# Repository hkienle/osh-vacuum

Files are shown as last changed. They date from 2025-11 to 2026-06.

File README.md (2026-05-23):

# Open Source Vacuum Cleaner

> **📝 Note:** This repository is currently being populated with information. Content and documentation are being added progressively.

---

## About

This repository contains the Open Source Vacuum Cleaner project, an open-source hardware and software solution for building custom vacuum cleaners. The project includes complete PCB designs, ESP32-S3 based firmware, and a web-based control interface.

The system is designed to control high RPM impellers for vacuum machines, featuring motor control, real-time monitoring (RPM, temperature, battery voltage), WiFi connectivity, and a modern web interface.

## Project Structure

```
osh-vacuum/
├── Hardware/              # PCB designs and hardware documentation
│   └── PCB_Bench_Prototype/  # Benchtop prototype board design
│       ├── README.md         # Hardware documentation and BOM
│       └── Production/       # Manufacturing files
├── Firmware/              # ESP32-S3 firmware and web interface
│   ├── README.md          # Firmware documentation, pin assignments, build instructions
│   ├── src/               # Firmware source code
│   └── ui/                # React-based web interface
└── README.md              # This file
```

### Hardware

The hardware design includes:
- ESP32-S3 microcontroller with WiFi and BLE
- Motor control with Infineon ProFet for high-side switching
- 5 RGB LEDs (WS2812B) and 3 customizable buttons
- Battery voltage monitoring (15-32V input)
- Temperature monitoring via thermistor
- Tachometer input for RPM measurement
- Break-off sections for flexible form factors

📖 **[Hardware Documentation →](Hardware/PCB_Bench_Prototype/README.md)**

### Firmware

The firmware provides:
- Motor speed control (0-100% PWM)
- Real-time monitoring (RPM, temperature, battery voltage)
- WiFi access point with web server
- WebSocket communication for live updates
- React-based web interface

📖 **[Firmware Documentation →](Firmware/README.md)**

## Quick Start

1. **Hardware**: Review the [PCB documentation](Hardware/PCB_Bench_Prototype/README.md) for board assembly
2. **Firmware**: Follow the [firmware build and upload instructions](Firmware/README.md)
3. **Frontend**: Build and upload the web interface as described in the firmware README

## Status

**Current Phase**: Benchtop Prototype

The current board design is untested and represents the benchtop prototype phase. All designs and firmware are provided as-is for development and testing purposes.

## License

This project is licensed under the **CERN Open Hardware Licence - Strongly Reciprocal (CERN OHL-S v2)**.

The full license text is available at: [cern_ohl_s_v2.txt](https://gitlab.com/ohwr/project/cernohl/-/wikis/uploads/819d71bea3458f71fba6cf4fb0f2de6b/cern_ohl_s_v2.txt)

---

*More information at [HackMD - Team Intuity](https://hackmd.io/@team-intuity) and [HackMD - hkienle](https://hackmd.io/@hkienle)*

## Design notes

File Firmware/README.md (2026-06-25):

# OSH Vacuum — Firmware

ESP32-S3 firmware for open-source high-RPM impeller vacuum machines.

→ **[Setup Guide](Setup.md)** — install, configure, build and flash  
→ **[Usage Guide](usage.md)** — operate the device, change settings

---

## What this firmware does

- **Motor control** — PWM-based speed control (0–100%) with ProFet high-side switching, configurable speed steps and minimum duty floor.
- **Two trigger modes** — Hold (hold-to-start, tap-to-stop) or Double-Press (momentary + latch).
- **Safety** — Automatic motor cutoff after a configurable runtime limit and on NTC over-temperature.
- **Sensors** — Real-time RPM (tachometer), motor NTC temperature, pack voltage, battery SOC, and ESP32 internal die temperature.
- **Battery SOC** — Rolling OCV-curve estimation from pack voltage ÷ series cell count. Paused while motor runs.
- **OLED display** — Supports 0.91" (SSD1306, 128×32) and 1.5" (SSD1327, 128×128) Waveshare I2C modules. Shows speed bar, live sensor value, battery icon, and OTA progress overlay.
- **LED strip** — 5 × WS2812B indicate WiFi status on boot, then display speed tier (blue = idle, red = motor active).
- **Dev / Settings menu** — 13-page on-device menu (hold UP+DOWN) with status pages and all configurable parameters. Settings persist in NVS.
- **WiFi** — STA mode with soft-AP fallback. mDNS via configurable hostname.
- **Web interface** — React SPA served from LittleFS on port 80. Real-time control and monitoring.
- **WebSocket telemetry** — JSON broadcast on port 81 at ~4 Hz (temp, battery, RPM, speed, motor state, SOC).
- **OTA updates** — ArduinoOTA (espota) for wireless firmware flashing via PlatformIO.
- **Light sleep** — Automatic power-saving after configurable inactivity timeout; wake on any button.

---

## Hardware at a glance

| GPIO | Function |
|---|---|
| 4 | Motor NTC thermistor (ADC) |
| 5 | Motor PWM output (LEDC, 1 kHz, 8-bit) |
| 6 | Battery voltage ADC (330 kΩ / 22 kΩ divider) |
| 7 | MOSFET / ProFet enable |
| 8 | I2C SCL (OLED) |
| 9 | I2C SDA (OLED) |
| 16 | Tachometer FG input (interrupt) |
| 39 | WS2812B LED data (5 LEDs) |
| 40 | Button DOWN |
| 41 | Button UP |
| 42 | Button TRIGGER |

---

## Project structure

```
Firmware/
├── platformio.ini                    # Build environments
├── data/                             # LittleFS contents (built web UI)
├── ui/                               # React frontend source
└── src/
    ├── main.cpp                      # Setup, loop, telemetry, safety
    ├── settings/                     # NVS runtime settings + compile-time config
    ├── motor/                      # Dispatcher + MOTOR_DRIVERS.md
    ├── motor_generic_pwm/          # LEDC PWM (default backend)
    ├── motor_xiaomi_g/             # Xiaomi G ESC: xiaomi_g_protocol, xiaomi_g_uart, driver
    ├── button/                       # Debounced inputs, trigger modes, dev menu
    ├── led/                          # WS2812B FastLED patterns
    ├── display/                      # Display facade + telemetry struct
    ├── display_oled/                 # SSD1306 128×32 rendering
    ├── display_waveshare_091_i2c/    # Adapter → display_oled
    ├── display_waveshare_15_i2c/     # SSD1327 128×128 rendering
    ├── battery/                      # ADC voltage + calibration
    ├── battery_soc/                  # OCV-based SOC estimation
    ├── temperature/                  # NTC thermistor (beta equation)
    ├── tachometer/                   # FG pulse counting → RPM
    ├── mcu_temp/                     # ESP32 internal die temperature
    ├── wifi/                         # STA/AP, mDNS
    ├── webserver/                    # AsyncWebServer, LittleFS
    ├── websocket/                    # WebSocket server, JSON telemetry
    ├── ota/                          # ArduinoOTA + display overlay
    └── power/                        # Light sleep, GPIO wakeup
```

---

## Libraries

| Library | Version | Purpose |
|---|---|---|
| FastLED | ^3.6.0 | WS2812B control |
| ArduinoJson | ^6.21.3 | JSON |
| WebSockets | ^2.4.1 | WebSocket server |
| ESPAsyncWebServer | ^3.8.1 | HTTP server |
| AsyncTCP | ^3.4.9 | Async TCP |
| ArduinoOTA | built-in | Wireless upload |
| Adafruit SSD1306 | latest | 0.91" OLED driver |
| Adafruit SSD1327 | latest | 1.5" OLED driver |
| Adafruit GFX Library | ^1.12.1 | OLED graphics primitives |

---

## License

Part of the Open Source Vacuum Cleaner project.

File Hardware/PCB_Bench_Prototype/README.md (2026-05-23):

# PCB Bench Prototype

**Status: Untested** - This board is currently in the benchtop prototype phase of the Open Source Vacuum Cleaner project and has not yet been tested.

## Overview

This PCB is designed to control a high RPM impeller for vacuum machines. It provides comprehensive control and monitoring capabilities with modern connectivity options.

The design features break-off sections that allow users to build their own vacuum cleaner in whichever shape they like. These break-off sections enable flexible placement of LEDs and buttons to suit various form factors and user preferences.

## Features

- **Connectivity**
  - BLE (Bluetooth Low Energy)
  - WiFi connectivity
  
- **Power Management**
  - USB-C connector for programming
  - Voltage regulation from 15-32V down to 5V and 3.3V
  - Battery voltage monitoring (reads voltage of connected battery)
  
- **User Interface**
  - 5 RGB LEDs (WS2812B)
  - 3 customizable buttons
  
- **Motor Control & Monitoring**
  - Automotive ProFet by Infineon for high-side switching (required for ESC control, replacing classic MOSFETs)
  - Level-shifted 3.3V and 5V PWM output
  - Voltage-divided input for 5V tachometer signal
  - 10kΩ thermistor reading capability
  
- **Expansion**
  - All unused and safe GPIOs are broken out
  - I2C, SPI, and UART interfaces available

## Bill of Materials (BOM)

| Designator | Footprint | Quantity | Value | LCSC Part # |
|---|---|---|---|---|
| C1, C7, C8, C9 | 0805 | 4 | 22µF | - |
| C10, C11, C12, C13, C14, C2, C5 | 0805 | 7 | 0.1µF | - |
| C3 | 0805 | 1 | 1µF | - |
| C4 | 0805 | 1 | 10nF | - |
| C6 | 0805 | 1 | 10µF | - |
| LED1, LED2, LED3, LED4, LED5 | LED-SMD_4P-L5.0-W5.0-TL-1 | 5 | WS2812B-V5/W | C2874885 |
| R10 | 0805 | 1 | 330kΩ | - |
| R11 | 0805 | 1 | 33kΩ | - |
| R12 | 0805 | 1 | 56kΩ | - |
| R13 | 0805 | 1 | 4.7kΩ | - |
| R14, R16 | 0805 | 2 | 5.1kΩ | - |
| R15, R17, R18, R3, R5, R6, R7, R8 | 0805 | 8 | 10kΩ | - |
| R4 | 0805 | 1 | 220Ω | - |
| R9 | 0805 | 1 | 22kΩ | - |
| SW1, SW2 | SW-SMD_4P-L4.2-W3.2-P2.15-LS4.6 | 2 | RKB2SJK250SMTRLFS | C2927789 |
| SW6, SW7, SW8 | KEY-SMD_4P-L5.2-W5.2-P3.7-LS6.4-TL | 3 | TS-1076S-A7B3 | C492950 |
| U1 | WIRELM-SMD_ESP32-S3-WROOM-1 | 1 | ESP32-S3-WROOM-1(N16R2) | C2913205 |
| U2 | PG-HSOF-8_L10.4-W9.8-BTH500151LUAAUMA1 | 1 | BTH500151LUAAUMA1 | C36571656 |
| U3 | SOT-223-4_L6.5-W3.5-P2.30-LS7.0-BR | 1 | LD1117S33CTR | C35879 |
| U4, U5 | SC-70-5_L2.0-W1.3-P0.65-LS2.1-BL | 2 | SN74AHCT1G125DCKR | C350557 |
| U8 | PWRM-TH_L11.7-W7.5_TSR1-2450 | 1 | TSR 1-2450_C6886877 | C6886877 |
| U9 | USB-SMD_TYPE-C16PIN-1 | 1 | 12402012E212A | C5150972 |

## Images

### Front View
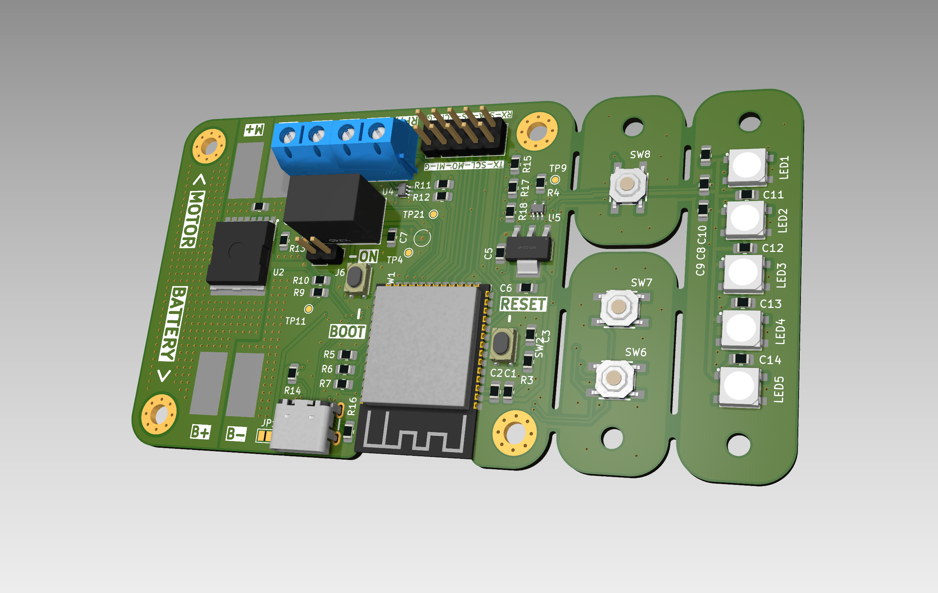
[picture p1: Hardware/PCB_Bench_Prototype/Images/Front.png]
Front View


### Back View
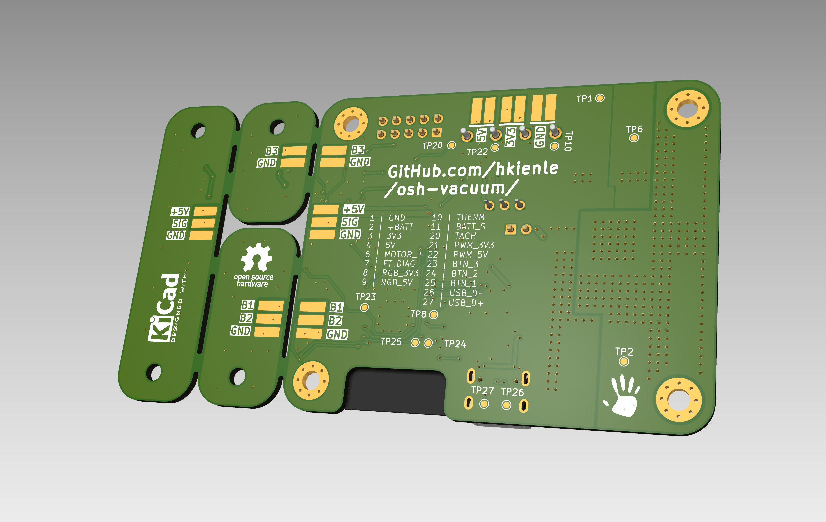
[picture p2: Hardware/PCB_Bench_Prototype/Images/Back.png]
Back View


### PCB Layout
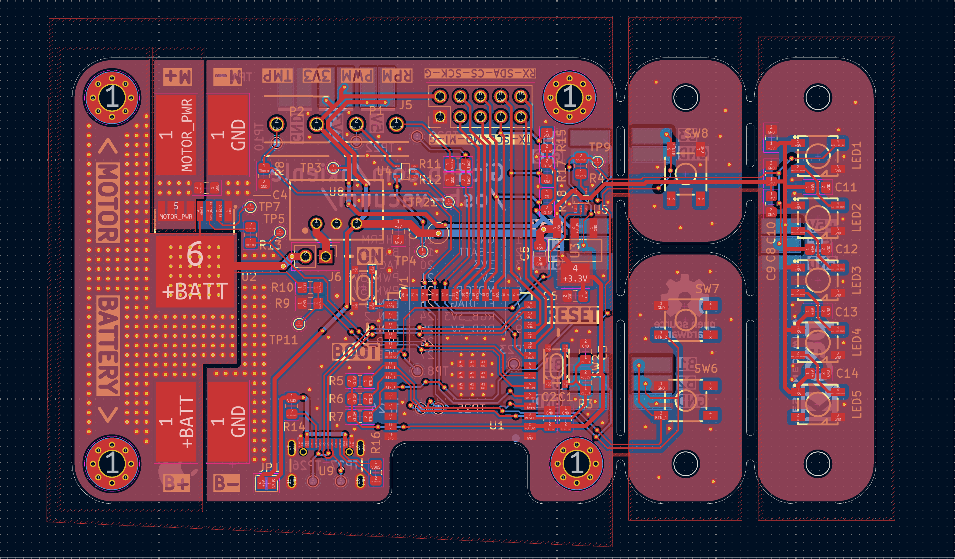
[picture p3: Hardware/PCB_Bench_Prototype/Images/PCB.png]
PCB Layout


## License

This hardware design is licensed under the **CERN Open Hardware Licence - Strongly Reciprocal (CERN OHL-S v2)**.

The full license text is available at: [cern_ohl_s_v2.txt](https://gitlab.com/ohwr/project/cernohl/-/wikis/uploads/819d71bea3458f71fba6cf4fb0f2de6b/cern_ohl_s_v2.txt)

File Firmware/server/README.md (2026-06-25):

# Hosted UI (separate from ESP web server)

The **hosted** React app is **not** the same as the UI baked into the ESP32 (LittleFS).

| | Embedded (ESP) | Hosted (this server) |
|---|---|---|
| **URL** | `http://osh-vac.local` | `http://your-server:8080` |
| **Static files** | LittleFS on ESP | `Firmware/ui/dist/` |
| **Device link** | Direct `ws://osh-vac.local:81` | Same-origin `/device-ws` proxy → vacuum |
| **Deploy** | `npm run build:esp32` + `uploadfs` | `npm run build:server` + run server below |

Browsers block an **HTTPS** hosted page from opening `ws://192.168.x.x:81` directly. The hosted server proxies WebSocket so the app stays same-origin.

## Quick start (local)

```bash
# 1. Build the hosted UI bundle
cd Firmware/ui
npm install
npm run build:server

# 2. Run the hosted server (static files + WebSocket proxy)
cd ../server
npm install
npm start
```

Open **http://localhost:8080** (not the ESP address).

1. Sidebar → **WiFi** (Bluetooth is not used yet)
2. Enter **`osh-vac.local`** or the vacuum's IP
3. **Connect via WiFi**

## Dev mode (Vite)

```bash
cd Firmware/ui
npm run dev
```

Open **http://localhost:5173** — the dev server includes the same `/device-ws` proxy.

## Production deploy

1. `npm run build:server` in `Firmware/ui`
2. Deploy `Firmware/ui/dist/` **and** run `Firmware/server/hosted.mjs` on your host (Node.js)
3. Put nginx/Caddy in front for HTTPS; ensure WebSocket upgrade works on `/device-ws`

**GitHub Pages (production):** see [docs/GITHUB_PAGES.md](../docs/GITHUB_PAGES.md) — static deploy at `https://connect.caznic.xyz` (BLE transport).

**Self-hosted (WiFi proxy):** run this server on your own host, or use `Firmware/Dockerfile` / `nixpacks.toml`.

Environment:

| Variable | Default | Purpose |
|---|---|---|
| `PORT` | `8080` | HTTP port |
| `UI_DIR` | `../ui/dist` | Path to built React app |

## ESP firmware

The vacuum still needs WiFi + WebSocket on port **81** (standard `esp32-s3` / `esp32-s3-ota` build). OTA only updates firmware; it does **not** update this hosted UI.

```bash
cd Firmware
pio run -e esp32-s3-ota -t upload
```

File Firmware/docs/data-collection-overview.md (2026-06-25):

# Data Collection Overview — Open Source Vacuum Cleaner

Comprehensive overview of all data the current build can collect — what's measured, what's computed, what's exposed, and what's hidden. Based on firmware source analysis (`Firmware/src/`) and PCB schematic (`Hardware/PCB_Bench_Prototype/`).

---

## 1. Directly Measured Sensor Data

Physical sensors connected to the ESP32-S3 via GPIO or internal peripherals.

| Data Point | Source / Sensor | GPIO | Update Rate | Resolution / Notes | Code Location |
|---|---|---|---|---|---|
| **Motor RPM** | FG tachometer pulse (ISR) | 16 | 5 Hz (200 ms) | 1 pulse/rev (`PULSES_PER_REV = 1`), ISR counting → Hz → RPM | `tachometer/tachometer.cpp` |
| **Motor temperature** | NTC thermistor 10k, Beta=3950 | 4 | 4 Hz (250 ms) | 8x oversampling, Beta equation, 12-bit ADC (0–4095), `SERIES_R = 10k` | `temperature/temperature.cpp` |
| **Pack voltage** | ADC voltage divider 330k/22k (ratio 16:1) | 6 | 10 Hz (100 ms) | 8x oversampling via `analogReadMilliVolts()`, 2-point calibrated (12V/36V), range 0–60V | `battery/battery.cpp` |
| **Pack voltage (raw)** | Same ADC, pre-calibration | 6 | 10 Hz | Uncalibrated divider output, available via `getBatteryVoltageRaw()` | `battery/battery.cpp:80-82` |
| **MCU die temperature** | ESP32-S3 internal sensor | internal | 2 Hz (500 ms) | `temperatureRead()` (Arduino core), returns °C or `NAN` before first read | `mcu_temp/mcu_temp.cpp` |
| **Battery SOC** | Derived from pack voltage | — | 2 Hz (100 ms sampling) | 21-point Li-ion OCV curve, rolling avg of 50 samples, **paused while motor runs + 2s cooldown** | `battery_soc/battery_soc.cpp` |

### Sensor Calibration Parameters

| Parameter | Value | Location |
|---|---|---|
| Voltage divider ratio | 330kΩ / 22kΩ = 16.0 | `battery/battery.cpp:7-9` |
| Voltage calibration points | 12.000V → 11.640V, 36.000V → 35.280V | `battery/battery.cpp:12-16` |
| NTC R0 | 10kΩ at 25°C | `temperature/temperature.cpp:15` |
| NTC Beta | 3950 | `temperature/temperature.cpp:17` |
| NTC series resistor | 10kΩ | `temperature/temperature.cpp:9` |
| Tachometer pulses/rev | 1 (configurable) | `tachometer/tachometer.cpp:7` |
| SOC OCV curve | 21 breakpoints, 3.520V (0%) → 4.080V (100%) | `battery_soc/battery_soc.cpp:21-28` |

---

## 2. Computed & Derived Data

Values calculated from sensor inputs, not directly measured.

| Data Point | Derivation | Update Rate | Persisted | Code Location |
|---|---|---|---|---|
| **Battery SOC %** | Pack voltage ÷ series cells → per-cell voltage → OCV curve interpolation → rounded 0–100 | 2 Hz (when motor off) | No (RAM only) | `battery_soc/battery_soc.cpp:128-143` |
| **Max RPM (session)** | Peak RPM while motor active | On motor on/off edge | Yes — NVS key `mstat_rpm` | `maximum_stats/maximum_stats.cpp:106-112` |
| **Max pack voltage (session)** | Peak voltage while motor active | On motor on/off edge | Yes — NVS key `mstat_vf` | `maximum_stats/maximum_stats.cpp:113-117` |
| **Max motor temp (session)** | Peak NTC temp while motor active | On motor on/off edge | Yes — NVS key `mstat_tf` | `maximum_stats/maximum_stats.cpp:118-124` |
| **Calibrated voltage** | Raw ADC → divider scale → 2-point linear correction | 10 Hz | No | `battery/battery.cpp:62-72` |
| **Cell voltage** | Pack voltage ÷ `batterySeriesCells` (1–32) | On SOC sample | No | `battery_soc/battery_soc.cpp:133` |
| **Auto-off elapsed** | `millis() - motorRunStartMs` compared to `autoOffMinutes` | Every loop | No | `main.cpp:128-137` |

---

## 3. Motor & Control State

State of the motor control subsystem (dispatcher with two backends).

| Data Point | Type | Values | Exposed | Code Location |
|---|---|---|---|---|
| **Motor active** | bool | true/false | WebSocket JSON, display, serial | `button/button.h:33-34` |
| **Speed setting** | uint8_t | 0–100% (in speed-step increments) | WebSocket JSON, display, serial | `button/button.h:24` |
| **PWM duty** | int | 0–255 | Display telemetry (not WebSocket) | `motor_generic_pwm/motor_generic_pwm.cpp:127-178` |
| **Motor running** | bool | true/false (internal LEDC/ESC state) | Display telemetry | `motor/motor.cpp:82-90` |
| **Motor type** | enum | `GenericPwm` (0) / `XiaomiG` (1) | Display telemetry, settings API | `settings/settings.h:52-55` |
| **Motor capabilities** | struct | `hasRpm`, `isDiscreteSpeed`, `overridesSpeedStep` | Internal only | `motor/motor_driver.h:22-26` |
| **Active driver name** | const char* | "Generic (PWM)" / "Xiaomi G" | Internal only | `motor/motor.cpp:161-166` |
| **RPM available** | bool | true (PWM) / false (Xiaomi-G) | Display telemetry | `motor/motor.cpp:104-120` |
| **Xiaomi-G ESC mode** | enum | Eco (0x01) / Medium (0x02) / High (0x03) | Internal only | `motor_xiaomi_g/xiaomi_g_protocol.h:12-16` |
| **Xiaomi-G cycle phase** | enum | IdleBeforeCtrl / WaitBeforeSetp | Internal only | `motor_xiaomi_g/motor_xiaomi_g.cpp:21-24` |
| **Motor run start time** | uint32_t | `millis()` at motor start | Internal only | `main.cpp:71,80-82` |
| **Speed levels list** | MotorSpeedLevels | 0/20/40/60/80/100% (PWM) or Off/Eco/Mid/Boost (Xiaomi) | Internal only | `motor/motor.cpp:122-128` |

### Per-Backend Differences

| Feature | Generic PWM | Xiaomi G |
|---|---|---|
| Speed control | Continuous PWM (LEDC, 1kHz, 8-bit) | Discrete ESC modes via UART (9600 8E1) |
| RPM available | Yes (from tachometer) | No (`getRpm()` returns 0.0) |
| Current draw | Not measured | Not parsed (RX frames unimplemented) |
| UART telemetry | N/A | TX only (CTRL + SETP frames sent, RX not read) |

---

## 4. Button & UI State

| Data Point | Type | Values | Exposed | Code Location |
|---|---|---|---|---|
| **Trigger pressed** | bool | true/false | Display telemetry | `button/button.h:30` |
| **Speed setting** | uint8_t | 0–100% | WebSocket, display | `button/button.h:24` |
| **Button activity flag** | bool | Set on any edge, cleared by power mgmt | Internal only | `button/button.h:21` |
| **Display info mode** | bool | Menu open/closed | Internal only | `button/button.h:38` |
| **Display info page** | uint8_t | 0–5 info, 6+ settings | Internal only | `button/button.h:39` |
| **Trigger mode** | enum | Hold (0) / DoublePress (1) | Settings API, display | `settings/settings.h:20-23` |

---

## 5. System & Diagnostic Data

| Data Point | Source | Update Rate | Exposed | Code Location |
|---|---|---|---|---|
| **Free heap** | `ESP.getFreeHeap()` | 4 Hz (250 ms) | Display telemetry only | `main.cpp:168` |
| **Uptime** | `millis() / 1000` | 4 Hz | Display telemetry | `main.cpp:167` |
| **WiFi link role** | `WiFiLinkRole` enum | On change | Internal only | `wifi/wifi.h:16,25` |
| **WiFi IP address** | `WiFi.localIP()` or `WiFi.softAPIP()` | On connect | Serial on boot | `wifi/wifi.cpp` |
| **WiFi RSSI** | `WiFi.RSSI()` | On demand | **Not exposed** (function exists: `getWiFiStaRssiDbm()`) | `wifi/wifi.cpp:85` |
| **WiFi hostname** | `DEVICE_HOSTNAME` | Static | Serial on boot | `wifi/wifi.h:31` |
| **WiFi network name** | SSID (STA) or AP SSID | On connect | Internal only | `wifi/wifi.h:37` |
| **OTA active** | bool | During OTA | Display telemetry | `main.cpp:170` |
| **OTA progress** | uint8_t % | During OTA | Display telemetry, LED bar | `main.cpp:171` |
| **Power/sleep state** | bool (return from `updatePowerManagement`) | Every loop | Internal only | `power/power.cpp:46-83` |
| **Thermal cutoff triggered** | bool | On event | LED blink pattern | `main.cpp:140-145` |
| **Auto-off triggered** | bool | On event | Serial log | `main.cpp:132-136` |

---

## 6. User Settings (NVS-Persisted)

All settings stored in NVS namespace `"oshvac"`. Persisted across reboots, editable via dev menu or WebSocket settings API.

| Key | Type | Range / Values | Default | Code Location |
|-----|---|---|---|---|
| `display_type` | String | "0.91-I2C-Waveshare" / "1.5-I2C-Waveshare" / "none" | Compile-time | `settings.cpp:9,24-26` |
| `bat_cells` | UChar | 1–32 (series cell count) | 5 | `settings.cpp:10` |
| `auto_off` | UChar | 0, 1, 2, 5, 10, 30 minutes | 2 | `settings.cpp:11` |
| `sleep_tmr` | UChar | 1, 2, 5, 10, 30 minutes | 2 | `settings.cpp:12` |
| `temp_lim` | UChar | 0 (off) or 30–70°C in 5° steps | 40 | `settings.cpp:13` |
| `spd_step` | UChar | 1, 5, 10, 20, 25 % | 20 | `settings.cpp:14` |
| `min_duty` | UChar | 0–30 % | 0 | `settings.cpp:15` |
| `max_duty` | UChar | 50–100 % (must be > min_duty) | 100 | `settings.cpp:16` |
| `mtr_disp` | UChar | 0=Speed, 1=Volt, 2=RPM, 3=MOT-Temp | 0 | `settings.cpp:17` |
| `trig_mode` | UChar | 0=Hold, 1=DoublePress | 1 | `settings.cpp:18` |
| `led_disp` | UChar | 0=SOC, 1=RPM, 2=Speed, 3=Temp | 2 | `settings.cpp:19` |
| `led_idle` | UChar | 0=SOC, 1=Speed, 2=RPM | 1 | `settings.cpp:20` |
| `led_dim` | UChar | 0–10% (1% steps), 15–50% (5% steps) | 5 | `settings.cpp:21` |
| `led_theme` | UChar | 0=Off, 1=White, 2=Blue, 3=Green, 4=Pink, 5=Orange, 6=Yellow | 1 | `settings.cpp:22` |
| `mtr_type` | UChar | 0=Generic (PWM), 1=Xiaomi G | 0 | `settings.cpp:23` |

**Additional NVS keys (max stats, same namespace):**

| Key | Type | Meaning |
|-----|---|---|
| `mstat_fl` | UChar | Flags: which max-stats are valid |
| `mstat_rpm` | UInt | Max RPM observed |
| `mstat_vf` | Float | Max pack voltage observed |
| `mstat_tf` | Float | Max motor temp observed |

---

## 7. Data Currently Exposed (Output Channels)

### 7.1 WebSocket Telemetry (4 Hz, port 81, JSON text)

Broadcast every 250 ms to all connected clients:

```json
{
  "temp": 25.50,
  "battery": 18.40,
  "rpm": 30000,
  "speed": 80,
  "motor_active": true,
  "battery_soc": 75
}
```

| Field | Unit | Source |
|---|---|---|
| `temp` | °C | Motor NTC thermistor |
| `battery` | V | Calibrated pack voltage |
| `rpm` | RPM | Tachometer (0 if Xiaomi-G) |
| `speed` | % | Speed setting (0–100) |
| `motor_active` | bool | Motor state |
| `battery_soc` | % | 0–100, or -1 if unavailable |

**Code:** `main.cpp:197-225`

### 7.2 Serial Output (4 Hz, 115200 baud)

Same subset as WebSocket, formatted as plain text:
```
Temperature: 25.50 / Battery: 18.40 / RPM: 30000 / Speed: 80%
```

**Code:** `main.cpp:203-207`

### 7.3 Display Telemetry (internal struct, richer than WebSocket)

The `DisplayTelemetry` struct (`display/display.h:6-47`) carries 30+ fields to the OLED rendering layer. **Not broadcast externally.** Includes everything in WebSocket plus:

- MCU temperature, free heap, uptime
- Battery series cells, all settings values, motor type
- Max stats (RPM, voltage, motor temp)
- OTA state, trigger held, display mode/page
- Speed step, min/max duty, trigger mode, LED config

### 7.4 Settings API (WebSocket, on-demand)

Full settings schema + values sent on `get_settings` command or after changes. ~8 KB JSON capacity.

**Code:** `websocket/websocket.cpp:80-101`, `settings_api.cpp`

### 7.5 OLED Display

Renders a subset of `DisplayTelemetry` depending on display mode:
- Speed bar, live sensor value (selectable: Speed/Volt/RPM/MOT-Temp), battery icon, OTA progress

---

## 8. Theoretically Collectible With Current Hardware (No New Components)

Data the ESP32-S3 and existing PCB can provide but that is **not currently exposed or logged**.

### 8.1 System Internals (ESP32 API, no wiring needed)

| Data Point | API Call | Available | Use Case |
|---|---|---|---|
| **Min free heap since boot** | `ESP.getMinFreeHeap()` | Yes, not used | Detect heap erosion / leaks |
| **Largest free block** | `ESP.getLargestFreeBlock()` | Yes, not used | Detect heap fragmentation |
| **CPU frequency** | `ESP.getCpuFreqMHz()` | Yes, not used | Diagnostic (typically 240 MHz) |
| **Chip revision** | `ESP.getChipRevision()` | Yes, not used | Hardware variant tracking |
| **Flash chip size** | `ESP.getFlashChipSize()` | Yes, not used | Build verification |
| **Flash chip speed** | `ESP.getFlashChipSpeed()` | Yes, not used | Diagnostic |
| **SDK version** | `ESP.getSdkVersion()` | Yes, not used | Build/firmware tracking |
| **Task stack high water mark** | `uxTaskGetStackHighWaterMark(NULL)` | Yes, not used | Detect stack overflow risk |
| **Free PSRAM** | `ESP.getFreePsram()` | Yes (N16R2 has 8MB), not used | Available for larger buffers |

### 8.2 WiFi / Network (functions exist, unused in telemetry)

| Data Point | API Call | Available | Use Case |
|---|---|---|---|
| **WiFi RSSI** | `getWiFiStaRssiDbm()` — already implemented | Yes, not broadcast | Link quality, range diagnostics |
| **WiFi BSSID** | `WiFi.BSSID()` | Yes, not used | Identify connected AP |
| **WiFi channel** | `WiFi.channel()` | Yes, not used | RF environment |
| **WebSocket client count** | `webSocket.connectedClients()` | Yes, not used | Connection monitoring |

### 8.3 Sensor Enhancements (existing hardware, firmware changes only)

| Data Point | How | Current State | Effort |
|---|-----|---|---|
| **RPM at higher rate** | Reduce `UPDATE_INTERVAL` from 200ms to 20ms, or switch to ISR timestamp method | 5 Hz, count-over-window | Low — firmware change |
| **Pulse-to-pulse RPM intervals** | Capture `micros()` in ISR, compute RPM from delta | Not implemented | Low — new ISR mode |
| **ADC raw values (pre-averaging)** | Expose individual `analogRead()` samples | Averaged internally | Low — expose in API |
| **ADC noise characterization** | Log raw samples for variance analysis | Not exposed | Low — debug mode |
| **Battery voltage raw** | `getBatteryVoltageRaw()` already exists | Function exists, not broadcast | Trivial — add to JSON |
| **Temperature raw ADC** | Expose `tempAcc / N` before Beta conversion | Not exposed | Low — add getter |

### 8.4 Xiaomi-G RX Telemetry (requires reverse engineering)

| Data Point | Status | Effort |
|---|---|---|
| **ESC status frames** | `0xAC 0x02 ...` frames received on GPIO18 but **not read or parsed** | Medium — RX parser + RE |
| **Motor current / torque** | Unknown if ESC reports this — needs logic analyzer capture | Unknown until RE |
| **ESC RPM** | Unknown if ESC reports this | Unknown until RE |
| **ESC temperature** | Unknown if ESC reports this | Unknown until RE |
| **ESC error flags** | Unknown if ESC reports this | Unknown until RE |
| **RX update rate** | Unknown — needed for watchdog timeout (3× rule) | Measure during RE |

**Note:** GPIO17/18 are both routed on the PCB and accessible on the J5 header. No hardware blocker. But the RX frame format, payload fields, and update rate are completely unknown. This is a standalone reverse-engineering workstream (~2–5 days with logic analyzer).

### 8.5 Internally Available But Not Broadcast

| Data Point | Where | Currently Used |
|---|---|---|
| PWM duty value (0–255) | `motorGenericPwmGetDuty()` | Internal only, not in WebSocket |
| Motor run duration | `millis() - motorRunStartMs` | Used for auto-off, not exposed |
| Motor capabilities flags | `MotorCapabilities` struct | Used internally for UI gating |
| Speed levels list | `motorGetSpeedLevels()` | Used for button up/down, not exposed |
| Active motor driver name | `motorActiveDriverName()` | Display only |
| Xiaomi-G current ESC mode | `s_currentMode` | Internal only |
| Power management state | `updatePowerManagement()` return | Internal only |

---

## 9. Data Requiring Hardware Expansion

Sensors not present on the current PCB. Listed by ML/bodenerkennung relevance.

### 9.1 High Priority (Roadmap Phase 0–1)

| Sensor | Interface | PCB Status | GPIO Needed | ML Value |
|---|---|---|---|---|
| **Motor current (INA226)** | I2C (shared with OLED on GPIO 8/9) | Not on PCB; I2C bus on J5 | ALERT pin → GPIO38 (wire solder) | Core feature for floor detection & anomaly detection |
| **IMU / vibration (MPU6050)** | I2C (shared) | Not on PCB; I2C bus on J5 | INT pin → free GPIO (wire solder) | Fallback if current+RPM insufficient for floor classification |

### 9.2 Medium Priority (Future Versions)

| Sensor | Interface | Use Case |
|---|---|---|
| **Differential pressure sensor** | I2C or analog | Airflow measurement, filter clog detection, suction power estimation |
| **Dust / particle counter** | I2C / UART | Dust concentration, air quality, filter load |
| **Bin fill level** | IR / ultrasonic / capacitive | "Bin full" detection, auto-stop |
| **Ambient temperature** | I2C (e.g., SHTC3) | Separate from motor NTC; contextual data |
| **Humidity sensor** | I2C (e.g., SHTC3, BME280) | Environmental context, condensation risk |

### 9.3 Lower Priority (Specialized)

| Sensor | Interface | Use Case |
|---|---|---|
| **Brush motor current** | ADC / INA226 | Brush blockage detection (only if brushed head) |
| **Microphone / acoustic** | I2S (ESP32-S3 supports) | Anomaly detection via sound signature (motor whine, blockage rattle) |
| **Load cell (weight)** | HX711 (GPIO) | Dust bin weight, fill estimation |
| **ToF / lidar distance** | I2C (VL53L0X) | Obstacle detection, surface profiling |

### 9.4 PCB Constraints for Expansion

| Constraint | Detail | Impact |
|---|---|---|
| **No free GPIOs on headers** | 16 unused GPIOs exist but none are broken out to J5 | Any new sensor needing an interrupt/ALERT pin requires wire soldering to an ESP32 module pad |
| **I2C bus available** | J5 exposes SDA (GPIO8) + SCL (GPIO9) + 3.3V + GND | INA226, MPU6050, and other I2C sensors can connect via J5 without board mods |
| **SPI bus available** | J5 exposes CS/MOSI/SCK/MISO (GPIO10–13) | Currently unused by firmware, available for SPI sensors |
| **PSRAM available** | ESP32-S3-WROOM-1 N16R2 has 8MB octal PSRAM | Usable for larger ring buffers or data caching (currently unused) |
| **No current sensing** | BOM has no INA226 or shunt | Motor current entirely unavailable on Generic-PWM builds without hardware addition |

---

## 10. Data Quality Assessment

Evaluation of each current data source against general and ML-specific requirements.

| Data Source | Rate | Resolution | Gaps | Assessment |
|---|---|---|---|---|
| Motor RPM (tachometer) | 5 Hz | 1 pulse/rev → integer RPM at typical speeds | **Too slow for 50 Hz feature sampling.** No signal at very low RPM (count = 0 in window). Xiaomi-G builds have no RPM at all. | Needs upgrade (ISR timestamp method or shorter window) |
| Motor temperature (NTC) | 4 Hz | ~0.1°C practical (12-bit ADC, 8x oversample) | Adequate for thermal protection. Slow thermal response — 4 Hz is sufficient. | Good for safety, limited ML value (too slow for floor changes) |
| Pack voltage | 10 Hz | ~0.05V (calibrated, 8x oversample) | Voltage sag under load could be informative but SOC sampling is **paused during motor run**. Raw voltage available but not logged. | Good rate. Enable logging during motor run for sag/load analysis. |
| Battery SOC | 2 Hz (motor off only) | 1% steps | **No SOC data during motor operation** — 2s cooldown after stop. Not usable for real-time ML. | By design (OCV requires rest). Acceptable for battery health, not for ML features. |
| MCU die temp | 2 Hz | ~1°C | Adequate for thermal monitoring. Correlates with ambient + CPU load. | Low ML value, useful for system health |
| Motor current | — | — | **Not measured at all** on current PCB | Critical gap for ML. Requires INA226 hardware addition. |
| Motor PWM duty | Loop rate | 8-bit (0–255) | Available internally but not exposed in telemetry | Trivial to expose. Useful as control-side feature. |
| Xiaomi-G telemetry | — | — | **RX not parsed** — no current, RPM, or status from ESC | Requires RE workstream. Potential high value if ESC reports current/torque. |

---

## 11. Recommendations for the ML Roadmap

Prioritized actions to improve data availability for the floor-detection and anomaly-detection prototype.

### Tier 1 — Do First (Firmware Only, No Hardware)

| Action | Effort | Impact |
|---|---|---|
| **Expose PWM duty in WebSocket JSON** | Trivial | Adds control-side feature for ML; shows what the controller is commanding |
| **Add `ESP.getMinFreeHeap()` and `ESP.getLargestFreeBlock()` to telemetry** | Trivial | Enables heap erosion/fragmentation detection over 1h test runs |
| **Add WiFi RSSI to telemetry** | Trivial — function `getWiFiStaRssiDbm()` already exists | Connection quality monitoring during data collection |
| **Upgrade tachometer to ISR-timestamp method** | Low (1–2 days) | Enables 50 Hz RPM sampling; much higher resolution for dRPM/dt features |
| **Implement chunked binary logging stream** | Medium (3–5 days) | 50 Hz feature logging without WiFi saturation (160 bytes/chunk at 5 Hz) |
| **Build Xiaomi-G RX parser** | Medium-High (3–7 days incl. RE) | Unlocks current/RPM/status telemetry for Xiaomi-G builds; eliminates feature-vector gap |

### Tier 2 — Hardware Addition (Breadboard / Wire Solder)

| Action | Effort | Impact |
|---|---|---|
| **Add INA226 current sensor on breadboard** | Low hardware, low firmware | Core ML feature: motor current + dI/dt. I2C via J5, ALERT on GPIO38 (wire). |
| **Add MPU6050 IMU on shared I2C** | Low hardware, medium firmware | Vibration features as fallback if current+RPM insufficient for floor classification |

### Tier 3 — Structural Improvements

| Action | Effort | Impact |
|---|---|---|
| **Introduce pre-sleep callback registry in `power/` module** | Low | Clean NVS persistence hook for cluster state before light sleep |
| **Add `[env:native]` PlatformIO build for ML modules** | Medium | Enables Python↔C++ equivalence testing without hardware |
| **Add per-loop timing instrumentation** | Low | Establishes inference budget baseline before ML integration |
| **Expose `battery_voltage_raw` in telemetry** | Trivial | Enables calibration drift detection over time |

### Key Insight

The single highest-impact gap is **motor current measurement** — it is the core feature for both floor detection (load signature per floor type) and anomaly detection (blockage, filter clog). On Generic-PWM builds this requires an INA226 on a breadboard (I2C via J5, ALERT wire to GPIO38). On Xiaomi-G builds, it requires reverse-engineering the RX protocol first. Until one of these is done, the ML prototype cannot produce meaningful floor classification from RPM and temperature alone.

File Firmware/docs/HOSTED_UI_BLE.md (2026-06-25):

# Hosted UI + Bluetooth Architecture

This branch (`feature/hosted-ui-ble`) moves the control UI off the ESP32 and connects over **Bluetooth Low Energy** instead of loading the SPA from LittleFS.

## Before vs after

| | Embedded (master) | Hosted + BLE (this branch) |
|---|---|---|
| UI hosting | LittleFS on ESP32 :80 | Static HTTPS server |
| Control link | WebSocket :81 over WiFi | BLE GATT (Nordic UART Service) |
| WiFi role | UI + telemetry + OTA | OTA / lab debugging (optional) |
| Phone use | Same WiFi network required | Direct BLE pairing |

## Firmware layers

```
main.cpp
  └── deviceLinkUpdate()
        ├── websocket/     (WiFi WebSocket :81 — optional fallback)
        └── ble/           (NimBLE NUS — primary for hosted UI)
              └── device_protocol/   (shared JSON command parser)
```

### BLE GATT (Nordic UART Service)

| UUID | Direction | Purpose |
|---|---|---|
| `6E400001-…` | Service | NUS |
| `6E400002-…` | Client → device (Write) | JSON commands, newline-terminated |
| `6E400003-…` | Device → client (Notify) | Telemetry, settings, acks |

Large payloads (settings schema ~6 KB) use `OV` fragment headers; the web client reassembles them.

### Build targets

- `esp32-s3` — BLE + embedded web UI (backward compatible)
- `esp32-s3-ble` — BLE-primary, **no** embedded web server (`OSHVAC_BLE_PRIMARY`)

```bash
pio run -e esp32-s3-ble -t upload
```

## Web UI transport abstraction

```
DeviceConnectionProvider
  ├── BleTransport      (Web Bluetooth API)
  └── WifiTransport     (WebSocket ws://ip:81)
```

Default transport:

- **HTTPS** hosted site → Bluetooth
- Embedded / local dev → WiFi

Override at build time: `VITE_DEFAULT_TRANSPORT=ble|wifi`

## Protocol (unchanged)

Same JSON messages as the original WebSocket implementation:

- Telemetry: `{ temp, battery, rpm, speed, motor_active, battery_soc }`
- Commands: `motor_start`, `motor_stop`, `heartbeat`, `get_settings`, `set_setting`, `{ speed }`

## Deployment checklist

1. Build UI: `cd Firmware/ui && npm run build:pages`
2. Deploy via GitHub Pages — see [GITHUB_PAGES.md](./GITHUB_PAGES.md) (`https://connect.caznic.xyz`)
3. Flash `esp32-s3-ble` (or `esp32-s3`) firmware
4. Pair from browser (Chrome/Edge, secure context)

## Known limits (MVP)

- Web Bluetooth is Chrome/Edge only; Safari support is limited
- BLE range vs WiFi — expect shorter distance, lower throughput
- OTA still uses WiFi (ArduinoOTA), not BLE
- Settings over BLE uses fragmentation; very poor RF may need retries

## Future work

- BLE provisioning (WiFi credentials from hosted UI)
- Optional WSS tunnel for WiFi-only browsers
- Drop LittleFS UI entirely on `esp32-s3-ble` to reclaim flash

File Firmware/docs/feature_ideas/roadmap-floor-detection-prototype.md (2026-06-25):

# Roadmap: KI-Bodenerkennung & Anomalie-Detection — Prototyp

Roadmap bis zum ersten funktionierenden Prototyp eines selbstlernenden Bodenerkennungs- und Wartungs-Diagnose-Systems für den Open-Source-Staubsauger.

## Prototyp-Scope

Der Prototyp ist bewusst eng geschnitten, um in 4–5 Wochen lieferbar zu sein:

- **Nur Generic-PWM-Builds** (LEDC-basiert wie aktuell)
- **Breadboard-INA226** als Stromsensor, kein PCB-Spin
- **Safety Schicht 1 via GPIO-Interrupt-Handler**, keine MCPWM-Migration
- **Xiaomi-G-Builds explizit ausgeschlossen**, weil RX-Parsing noch nicht existiert und kein RPM verfügbar ist
- **Sprache des Codes: Englisch**, konsistent zur bestehenden Codebase. Dieses Roadmap-Dokument bleibt Deutsch.

Alles weitere (MCPWM, PCB-Revision, Xiaomi-G-Support, Auto-Power-Anpassung, Daten-Spende) ist explizit v1.0 oder später — siehe Abschnitt "Out of Prototype Scope".

## Architektur-Übersicht

Das ML-System besteht aus drei aufeinander aufbauenden Schichten:

1. **Self-Calibration** — Beim ersten Boot misst das Gerät seinen eigenen Leerlauf-Baseline (RPM und Strom bei verschiedenen Duty-Stufen). Damit werden alle Sensordaten Build-unabhängig normalisiert.

2. **Distanzbasiertes inkrementelles Clustering** — Während des Saugens gruppiert das Gerät seine Sensordaten in Cluster. Cluster werden nur erzeugt, wenn neue Datenpunkte einen Distanz-Schwellwert zu allen bestehenden Centroiden überschreiten. Keine fixe Cluster-Zahl, keine Labels.

3. **Anomalie-Detection mit Suspicious-Buffer** — Punkte außerhalb der bekannten Cluster werden zunächst gepuffert und über Varianz und Plausibilität klassifiziert: stabile, plausible Werte führen zu einem neuen Cluster-Spawn, instabile oder physikalisch implausible zu einer Anomalie-Meldung.

Optional kann der Nutzer Cluster in der Web-UI benennen — nicht erforderlich für Funktion.

## Safety-Architektur (drei Schichten)

Die ML-Schicht darf niemals der einzige Schutz vor Hardware-Schaden sein.

**Schicht 1 — Hardware-nahe Reaktion (Mikrosekunden):**

Im Prototyp via **GPIO-Interrupt-Handler** mit hoher Priorität. INA226 ALERT-Pin geht auf einen freien GPIO mit Interrupt, der ISR zieht direkt den ProFet-Enable-Pin low. Reaktionszeit Mikrosekunden — für Motor-Schutz absolut ausreichend.

MCPWM-Fault-Trip-Mapping wird auf v1.0 verschoben zusammen mit der PCB-Revision (sub-Mikrosekunden, aber erfordert Migration `motor_generic_pwm/` von LEDC auf ESP-IDF-MCPWM, was eigene Risiken hat).

**Schicht 2 — Firmware-Loop (Millisekunden):**

Im Loop läuft vor allem ML-Code ein simpler Hard-Check: absolute Grenzwerte für Strom, Temperatur, Spannung. Werden sie überschritten → sofortiger `setMotorState(false)`. Grenzwerte sind pro Build fest hinterlegt und werden **nicht** aus dem ML-Modell abgeleitet. Die bestehende Temperatur-Cutoff-Logik in `main.cpp` ist exakt dieses Pattern — wird um Strom und Spannung erweitert.

**Schicht 3 — ML-Schicht (Sekunden):**

Anomalie-Erkennung wie unten beschrieben. Findet feinere Probleme (Filter zu, Bürste blockiert, Socke), die Hardware-Limits nicht auslösen.

Wenn ein ML-Bug das Modell crasht, schützen Schichten 1 und 2 die Hardware trotzdem.

## Backend-Dispatcher-Pattern

Die bestehende Firmware nutzt für Motor-Module ein Dispatcher-Pattern (`motor/motor.cpp` mit `motor_generic_pwm/` und `motor_xiaomi_g/` Backends hinter `MotorDriver`-vtable). Diesem Pattern folgen die neuen Module.

Im Prototyp wird das `current/`-Modul als Dispatcher angelegt, aber **nur das `current_ina226/`-Backend implementiert**. Das `current_xiaomi_g/`-Backend bleibt als Header-Stub für v1.0 reserviert. So entsteht keine Architektur-Schuld, nur eine verschobene Implementierung.

## Übergeordnete Design-Prinzipien

**Relative Schwellwerte, keine absoluten Werte.** Das System ist hardware-agnostisch. Alle Schwellwerte für Klassifikation, Spawn, Anomalie und Plausibilität werden aus der Kalibrierungs-Baseline berechnet (`Threshold = Baseline_Reference * Faktor`).

**Statische Speicher-Allokation.** Alle Puffer (Ringpuffer, Suspicious-Buffer, Cluster-Centroids) werden zur Compile-Zeit allokiert. Kein `new`/`malloc` im Loop.

**Watchdog-Timeouts als 3× nominale Update-Rate.** Jeder Sensor-Watchdog bekommt einen Timeout von mindestens 3× der nominellen Sample-Rate.

**NVS-Schreibvorgänge minimieren.** Adaption-State wird in RAM gehalten und nur bei Light-Sleep oder maximal alle 60 Minuten persistiert.

**NVS-Namespace-Trennung.** Calibration-Daten landen in einem eigenen Namespace `calib`, Cluster-Centroids in `floor`. Keine Kollision mit bestehenden `settings`-Keys.

## Anomalie-Pipeline State Machine

```mermaid
stateDiagram-v2
    [*] --> Normal
    Normal --> Transition: |dI/dt| > Schwellwert
    Transition --> Normal: Ableitung beruhigt sich
    Transition --> Suspicious: Timeout 1s erreicht
    Normal --> Suspicious: Punkt außerhalb 3sigma aller Cluster
    Suspicious --> Spawn: Niedrige Varianz + plausibler Wertebereich
    Suspicious --> Anomalie: Hohe Varianz ODER unplausibel
    Suspicious --> Normal: Punkt kehrt in bekanntes Cluster zurück
    Spawn --> Normal: Cluster initialisiert
    Anomalie --> Persistent: N konsekutive Samples
    Anomalie --> Normal: Spike vorbei
    Persistent --> [*]: Warnung an User
```

Während Transition wird weder Anomalie noch Spawn ausgelöst. Während Suspicious wird kein Cluster aktualisiert. Anomalie-Punkte werden vom Cluster-Update generell ausgeschlossen (Anomaly-Aware Learning).

## Annahmen

- 3-Personen-Team mit AI-assistiertem Coding
- Bestehende Firmware-Basis (ESP32-S3, WebSocket auf Port 81, NVS-Settings im Namespace `oshvac`, React-UI auf LittleFS)
- Breadboard-INA226 für Prototyp-Tests, kein PCB-Spin nötig
- Nur Generic-PWM-Motor

## Code-validierte Fakten (Stand Investigation)

Diese Punkte sind gegen die Codebase verifiziert und müssen die Phase-0-Planung konkret bestimmen:

- **INA226 ALERT → GPIO38** per Drahtverbindung direkt am ESP32-Pin. Keiner der 16 freien GPIOs ist auf den J5-Header geführt, daher Lötaktion zwingend
- **Tachometer-Update-Rate aktuell 5 Hz** (`UPDATE_INTERVAL = 200ms`). Muss auf ISR-Zeitstempel-Verfahren umgestellt werden für brauchbare Feature-Sampling-Rate
- **Kein Pre-Sleep-Hook im `power/`-Modul** vorhanden. Callback-Registry analog zu `RuntimeSettingsChangedCallback` muss eingeführt werden
- **Keine Firmware-Test-Infrastruktur**. Kein `[env:native]`, kein Unity/Doctest. Muss als Teil von Phase 0 / Phase 2 aufgesetzt werden
- **Heap-Monitoring nur via `ESP.getFreeHeap()`** — keine Fragmentation-Erkennung. `getMinFreeHeap()` und `getLargestFreeBlock()` ergänzen
- **Keine Loop-Timing-Instrumentierung** — schätzungsweise Sub-Millisekunde, aber muss gemessen werden
- **Pin-Mapping-Diskrepanzen** zwischen KiCad-Schematic und Firmware-Header bei UART (RX/TX-Labels) und I2C (SDA/SCL-Labels). Vor Hardware-Modifikationen verifizieren
- **WebSocket-Library** unterstützt `sendBIN()` mit 15 KB Frame-Limit (keine Send-Fragmentation), reicht für 160-Byte-Chunks weit aus
- **React-UI ist reiner Text/JSON-Client** ohne Binary-Frame-Handling. Python-Logger läuft daher als direkter WebSocket-Client vom Laptop, nicht via UI

## Phasenübersicht

| Phase | Inhalt | Dauer |
|---|---|---|
| 0 | Setup, Kalibrierung, Safety-Foundation, Firmware-Foundation | 1,5 Wochen |
| 1 | Datensammlung (light) | 1 Woche |
| 2 | Modell-Pipeline (Clustering + Anomalie) | 1,5 Wochen |
| 3 | On-Device-Integration | 1 Woche |

**Gesamt:** 5 Wochen netto, 6 Wochen mit Puffer.

---

## Phase 0 — Setup, Kalibrierung, Safety- & Firmware-Foundation

**Ziel:** Hardware-Safety etabliert, Kalibrierung robust, normalisierte Features fließen sauber durch, Firmware-Infrastruktur für ML-Module bereit.

**Aufgaben — Verifikation & Infrastruktur:**

- **Pin-Mapping verifizieren** für UART (Schematic-Labels RX/TX vs. Firmware-Konstanten) und I2C (SDA/SCL). Aktuelle Kommunikation gegen Hardware testen, bevor weitere Mods erfolgen
- **Loop-Timing-Instrumentation**: `micros()`-basiertes Benchmarking pro Loop-Iteration einbauen, Durchschnitt und Worst-Case in Telemetrie
- **Heap-Monitoring** ergänzen: `ESP.getMinFreeHeap()` und `ESP.getLargestFreeBlock()` in `DisplayTelemetry` und WebSocket-JSON aufnehmen. Damit wird Fragmentation über Stunden sichtbar
- **Pre-Sleep-Callback-Registry im `power/`-Modul** einführen, analog zum bestehenden `RuntimeSettingsChangedCallback`-Pattern. Module registrieren sich via `registerPreSleepCallback(fn)`, `power.cpp` iteriert vor `esp_light_sleep_start()`. Notwendig für saubere NVS-Persistierung in Phase 3
- **PlatformIO `[env:native]` aufsetzen** als zweites Build-Target, gegen Desktop-GCC. Architektur-Constraint: ML-Module dürfen keine Arduino-Dependencies haben (Feature-Extraktor und ML-Logik operieren nur auf statischen Float-Vektoren). Foundation für Phase-2 Equivalence-Test-Harness

**Aufgaben — Sensorik:**

- **Tachometer-Upgrade**: Umstellung vom Count-over-Window-Verfahren (5 Hz) auf **ISR-Zeitstempel-Verfahren** (Pulse-to-Pulse-Intervall). Sauberer und skaliert besser zu höheren RPM. Effektive Sample-Rate steigt deutlich, nutzbar für 50-Hz-Feature-Sampling
- **Breadboard-INA226** an I2C-Bus (GPIO 8/9, auf J5-Header verfügbar) anschließen. **ALERT-Pin via Drahtverbindung an GPIO38** löten (nicht auf Header geführt, daher Lötaktion direkt am ESP32-Pin)
- **Modul `current/` als Dispatcher anlegen** mit zwei Backend-Stubs:
  - `current_ina226/` — voll implementiert (I2C-Treiber, ALERT-Konfiguration, GPIO38-Interrupt)
  - `current_xiaomi_g/` — Header-Stub als Platzhalter für v1.0

**Aufgaben — Safety:**

- **Safety Schicht 1: GPIO-Interrupt-Handler** auf GPIO38 mit hoher Priorität, zieht ProFet-Enable direkt low. Konfigurations-Schwellwert wird nach Kalibrierung gesetzt (z.B. 2× Nennstrom bei 100 % Duty)
- **Safety Schicht 2** aktivieren: absolute Strom-/Spannungs-Grenzwerte als Loop-Check, analog zur bestehenden Temperatur-Cutoff-Logik

**Aufgaben — Kalibrierung & Features:**

- **Kalibrierungs-Routine** (Modul `calibration/`): Motor durch Duty-Stufen 25/50/75/100 % rampen, Leerlauf-RPM und Leerlauf-Strom mitteln. **Plausibilitätsprüfung** integriert. Persistenz im neuen NVS-Namespace `calib`
- **Web-UI** um "Kalibrieren"-Seite ergänzen
- **Feature-Extraktor** in C++ (Arduino-frei!) und Python parallel implementieren. Statische Ringpuffer für Ableitungen über 100 ms und 500 ms Fenster. Normalisierung gegen Kalibrierungs-Baseline

**Aufgaben — Logging-Pipeline:**

- **Höher-getakteter Logging-Stream**: bestehendes WebSocket auf Port 81 um `broadcastBIN()`-Pfad erweitern. Effektiv 50 Hz, chunked als 5-Hz-Pakete à 10 Samples binär. Bleibt unter dem 15-KB-Frame-Limit
- **Python-Logger als direkter WebSocket-Client** vom Laptop, nicht via React-UI. UI-Binary-Support wird bewusst auf v1.0 verschoben
- **ML-Repo** aufsetzen (Notebooks, Datenformat, Dependencies)

**Gate Phase 0:**

- Pin-Mappings verifiziert, Diskrepanzen dokumentiert oder behoben
- Loop-Timing und Heap-Monitoring sind in Telemetrie sichtbar
- Pre-Sleep-Callback-Registry funktioniert
- `[env:native]` baut die ML-Module Arduino-frei
- Tachometer liefert hochfrequente Updates
- Hardware-Safety-Schicht 1 funktioniert: künstlicher Überstrom triggert Motor-Stopp via GPIO38-Interrupt (verifizierbar mit Logic Analyzer)
- Safety-Schicht 2 stoppt bei Verletzung absoluter Grenzwerte
- Gerät kalibriert sich, lehnt unplausible Kalibrierungen ab, persistiert in `calib`-Namespace
- Normalisierte Features inkl. Ableitungen werden über chunked Binary-WebSocket gebroadcastet
- Python-Logger speichert sauber in Parquet

---

## Phase 1 — Datensammlung (light)

**Ziel:** Genug echte Saug-Daten, um die Cluster-Sinnhaftigkeit lokal pro Gerät zu validieren. **Validiert wird Cluster-Qualität pro Wohnung, nicht Generalisierung** — letztere ist erst v1.0-Thema mit Community-Datensatz.

**Aufgaben:**

- 2–3 Stunden normales Saugen pro Wohnung, verteilt über mindestens 3 Wohnungen
- Verschiedene Akkustände abdecken
- Provozierte Fehlerszenarien: Bürste blockieren, Filter teilweise abdecken, Schlauch zuhalten, Übergangsphasen zwischen Bodentypen
- Leichtes Labeling für spätere Validierung
- Parallel: Erste Datenexploration im Notebook, prüfen ob distanzbasiertes Clustering sinnvolle Gruppen ergibt

**Gate Phase 1:**

- ~6–8 h Daten gesamt über 3 Wohnungen
- Cluster bilden visuell erkennbare Bodentyp-Gruppen
- Provozierte Fehler heben sich klar vom Normal-Korridor ab

---

## Phase 2 — Modell-Pipeline

**Ziel:** Algorithmen sind ausgewählt, parametrisiert, in Python wie in C++ funktional und verifiziert äquivalent.

**Aufgaben:**

- **Distanzbasiertes inkrementelles Clustering**: Cluster werden nur erzeugt bei Distanz-Schwellwert-Überschreitung zu allen bestehenden Centroiden. Zwischen 1 und 8 Cluster, sehr langsame Lernrate für Centroid-Adaption
- **Suspicious-Buffer-Mechanismus** für Spawn vs. Anomalie:
  - Statischer Ringpuffer (z.B. 2 Sekunden)
  - In Pufferphase: kein Update, keine Meldung
  - Nach Persistenz-Schwelle Klassifikation:
    - Niedrige Varianz UND plausibler Wertebereich (relativ zur Kalibrierung) → Spawn
    - Hohe Varianz ODER unplausibler Wertebereich → Anomalie
  - Optional UI-Bestätigung bei Spawn
- **Anomaly-Aware Learning**: Anomalie-Samples werden vom Cluster-Update ausgeschlossen
- **Transitions-Gate mit 1-Sekunden-Timeout**: Bei hohen Ableitungen Anomalie-Detection unterdrücken, aber maximal 1 Sekunde
- **Bounding-Box mit asymmetrischer Korridor-Erweiterung**: Bei Drift-Anschlag friert Cluster ein, Erkennungs-Korridor erweitert sich in Drift-Richtung (+6σ), UI spielt Re-Kalibrierungs-Empfehlung aus
- **Anomalie-Persistenz-Schwelle**: Anomalie wird erst nach N konsekutiven Samples gemeldet
- **Validierung auf gesammelten Daten**: Cluster vs. Labels, Anomalie-Trefferquote, keine False-Positives bei Übergängen
- **Hyperparameter festklopfen**: Distanz-Schwellwert, Lern-Rate, Persistenz-Schwellen, dI/dt-Schwellwert, Bounding-Box-Radius, Plausibilitäts-Faktoren
- **C++-Port** der Algorithmen, statische Allokation, deterministisch, **Arduino-frei** (operiert nur auf statischen Float-Vektoren)
- **Python↔C++ Equivalence Test Harness**: dockt am in Phase 0 aufgesetzten `[env:native]` an. C++-CLI-Tool liest Feature-Vektoren aus CSV, Python-Skript füttert beide Implementierungen mit identischen Eingaben, Vergleich via `numpy.allclose()` mit definierter Floating-Point-Toleranz

**Gate Phase 2:**

- Python-Pipeline klassifiziert Test-Daten konsistent
- Spawn-Mechanismus erzeugt Cluster für stabile Böden, nicht für Anomalien
- Anomalie-Detection erkennt provozierte Fehler ohne False-Positives bei Übergängen
- Bounding-Box-Mechanismus verhält sich korrekt
- Equivalence-Harness bestätigt C++↔Python-Übereinstimmung

---

## Phase 3 — On-Device-Integration

**Ziel:** Komplettes System läuft on-device über eine Saug-Session.

**Aufgaben:**

- Modul `floor_detection/` in Firmware integrieren, läuft im Loop. Intervall basierend auf in Phase 0 gemessenem Loop-Timing-Budget (initial 250 ms, anpassen falls Inferenz-Zeit es zulässt oder erfordert)
- Modul `anomaly/` mit Persistenz-Schwelle und LED-/Display-Warnung
- Aktuelle Cluster-ID und Anomalie-Status in `DisplayTelemetry` und WebSocket-JSON aufnehmen
- **NVS-Persistenz-Strategie**:
  - Cluster-Centroids und Adaption-State in RAM
  - Persistierung im `floor`-Namespace via Pre-Sleep-Callback (in Phase 0 eingeführt)
  - Backup alle 60 Minuten als Power-Loss-Schutz
- Web-UI: Cluster-Nutzungsstatistik, Eingabefeld zum Benennen, Re-Kalibrierungs-Empfehlung bei Bounding-Box, Spawn-Bestätigungs-Dialog
- Benchmark: Inferenzzeit pro Iteration, Heap (konstant über Zeit), kein Memory-Leak
- **1-Stunden-Dauerlauf**: kein Crash, kein Heap-Wachstum
- Live-Test: Wohnung durchsaugen, Cluster-Wechsel beim Bodentyp-Wechsel, Bürste-Blockade triggert Warnung, normaler Übergang nicht

**Optionale Phase-3-Optimierung (falls Inferenzzeit klemmt):** ML-Update auf Core 0 via `xTaskCreatePinnedToCore`, Motor-Control bleibt auf Core 1. Direkte Antwort auf das Performance-Risiko, aber nur wenn Benchmark-Daten es erfordern.

**Gate Phase 3 (= Prototyp fertig):**

- Self-Calibration funktioniert beim ersten Boot
- Distanzbasiertes Clustering läuft stabil über eine Saug-Session
- Anomalie-Detection erkennt Fehler ohne False-Positives bei Übergängen
- Hardware-Safety-Schichten 1 und 2 greifen bei künstlichen Fehlerzuständen
- 1 Stunde Dauerlauf, Heap konstant

---

## Out of Prototype Scope (v1.0+)

Bewusst aus dem Prototyp ausgeschlossen, um den Scope kontrolliert zu halten:

- **Xiaomi-G-Support** — erfordert RX-Frame-Parsing (existiert nicht), Reverse-Engineering oder Doku des ESC-Protokolls, eventuell PCB-Anpassung falls RX-Leitung nicht verdrahtet. Wird als komplettes eigenes Workstream behandelt
- **MCPWM-Migration** für Sub-Mikrosekunden Safety Schicht 1 — Paradigmenwechsel weg von Arduino-LEDC zu ESP-IDF-Peripheral-Level. Kommt zusammen mit der PCB-Revision
- **PCB-Revision** mit integriertem INA226, geroutetem ALERT → MCPWM-Fault-Input, Footprint für optionalen IMU
- **Auto-Power-Anpassung**: Erkennung Teppich → Duty hoch, Hartboden → runter, mit Hysterese
- **Filter-Health-Score** basierend auf Drift des Normal-Korridors über Zeit
- **Daten-Spende-Pfad** für gemeinsamen OSS-Datensatz, später Cold-Start-Modell
- **IMU als zusätzliches Sensor-Backend** falls Phase 1 zeigt, dass Strom + RPM nicht reichen
- **Englische Übersetzung** dieses Dokuments für die OSS-Community
- **React-UI Binary-Frame-Support** für Live-Visualisierung des Sensor-Streams im Browser (Prototyp nutzt Python-Logger)
- **Pin-Mapping-Diskrepanzen** in Schematic/Firmware sauber harmonisieren (UART-Labels, I2C-Labels) im Zuge der PCB-Revision

## Risikohinweise

- **Wenn das in Phase 0 gemessene Loop-Timing zeigt, dass die Iteration knapp am Budget ist**: ML-Inferenz von vornherein auf Core 0 via `xTaskCreatePinnedToCore` verlagern, statt es als Phase-3-Optimierung zu behandeln
- **Wenn das ISR-Zeitstempel-Verfahren am Tachometer auf bestimmten Motoren ungewöhnliches Jitter zeigt**: Fallback auf 20-ms-Count-over-Window-Verfahren, dafür verrauschter, aber robust
- **Wenn die Pin-Mapping-Verifikation Konflikte aufdeckt** (z.B. OLED kommuniziert tatsächlich auf vertauschten Pins): Verzögerung um 0,5–1 Tag plus eventuell Firmware-Korrektur
- **Wenn `[env:native]` Konflikte mit Arduino-Dependencies in Nachbar-Modulen produziert**: Striktes Trennen via Header-Interface zwischen Sensor-Layer und ML-Layer
- **Wenn in Phase 1 die Cluster sich nicht sauber trennen lassen**: IMU als zusätzliches Backend-Modul am gemeinsamen I2C-Bus. Eine Woche extra
- **Wenn distanzbasierter Spawn zu konservativ ist**: Schwellwert anpassen oder Spawn nach kürzerer Persistenz erlauben mit zwingender UI-Bestätigung
- **Wenn der Logging-Stream trotz Chunking WiFi sättigt**: Sample-Rate temporär reduzieren oder im seltenen Fall auf separaten Raw-TCP-Socket umsteigen
- **Wenn die GPIO38-Drahtverbindung mechanisch unzuverlässig wird**: Festere mechanische Lösung (winziges Aufsteck-Board oder direkter Solder-to-PCB) — für Prototyp-Phase aber unproblematisch

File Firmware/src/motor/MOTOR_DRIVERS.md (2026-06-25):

# Motor drivers (modular backend)

## What this is

Motor control is split into **small modules** (`motor_<name>/`) behind a single API in [`motor/motor.h`](motor.h). Firmware code never includes a specific driver; it calls `initMotor()`, `setMotorSpeedPercent()`, `motorGetRpm()`, etc. The active driver is selected by `RuntimeSettings::motorType` (NVS key `mtr_type`).

```text
main / button / power / websocket / display
              │
              ▼
        motor/motor.cpp   ← dispatcher
              │
    ┌─────────┴─────────┐
    ▼                   ▼
motor_generic_pwm/   motor_xiaomi_g/  …
```

## Module layout

| Location | Role |
|---|---|
| [`motor/motor.h`](motor.h), [`motor.cpp`](motor.cpp) | Public API, active driver pointer, `motorNextSpeedPercent` / `motorPrevSpeedPercent`, NVS-driven menu visibility |
| [`motor/motor_driver.h`](motor_driver.h) | `MotorDriver` vtable, `MotorCapabilities`, `MotorSpeedLevels`, `supportsGlobalSetting`, `driverSettings` |
| [`motor_generic_pwm/`](../motor_generic_pwm/) | LEDC PWM on GPIO 5; RPM from tachometer |
| [`motor_xiaomi_g/`](../motor_xiaomi_g/) | ESC UART on TX 17 / RX 18 (`Serial2`, 9600 8E1); see below |
| [`settings/dev_menu.h`](../settings/dev_menu.h) | `DevSettingId`, `DevSettingDescriptor` (dev-menu pages are table-driven) |

Add a new driver: create `src/motor_foo/motor_foo.{h,cpp}`, export `extern const MotorDriver kFooDriver;`, register it in `motorDriverForType()` in [`motor.cpp`](motor.cpp), and extend `MotorType` + NVS clamp in [`settings.h`](../settings/settings.h) / [`settings.cpp`](../settings/settings.cpp).

## `MotorDriver` vtable (contract)

| Field | When called | Purpose |
|---|---|---|
| `name` / `nvsValue` | — | UI label; `nvsValue` should match `motorTypeToString()` for that type |
| `init` / `deinit` | `initMotor()` / driver swap | Hardware setup / teardown |
| `update` | Every `loop` → `updateMotor()` | Heartbeats, UART RX, timeouts |
| `onPowerOn` / `onPowerOff` | First `startMotor` / `stopMotor` while motor type is non-PWM* | Avoid per-loop spam; see dispatcher |
| `setSpeedPercent` | Main loop when motor active | Map UI 0–100 % to hardware |
| `isRunning` | Optional | Running state (generic PWM uses internal LEDC state) |
| `getRpm` / `isRpmReady` | Telemetry if `caps.hasRpm` | PWM delegates to `tachometer/` |
| `getSpeedLevels` | UP/DOWN speed steps | Discrete or synthesized level list |
| `handleWebSocketCommand` / `handleHeartbeat` | WebSocket | Legacy/raw commands |
| `supportsGlobalSetting` | Dev-menu rebuild | `false` → hide that global NVS setting page |
| `driverSettings` | Dev-menu rebuild | Extra `DevSettingDescriptor` rows (NVS in driver TU) |

\*Non-PWM drivers: `startMotor()` / `stopMotor()` only latch `onPowerOn` / `onPowerOff` once per run/stop (see [`motor.cpp`](motor.cpp)).

## Capabilities

| Flag | Effect |
|---|---|
| `hasRpm` | If `false`, `motorGetRpm()` / `motorIsRpmReady()` are gated off; UI should show `--` |
| `isDiscreteSpeed` | Hints that labels may be non-linear (e.g. Eco / Mid / Boost) |
| `overridesSpeedStep` | Speed list comes only from `getSpeedLevels`, not from `speedStepPercent` |

## Speed levels

- **Generic PWM:** `getSpeedLevels()` builds `0, step, 2·step, …, 100` from `speedStepPercent` (same stepping as before).
- **Discrete (e.g. Xiaomi):** Return constant table `{ Off, Eco, Mid, Boost }`; percent bands map to ESC MM: Eco / Medium / High (see `xiaomi_g_protocol.cpp`).
- **Buttons:** `motorNextSpeedPercent` / `motorPrevSpeedPercent` walk that list.

## Hiding global dev-menu settings

Implement `supportsGlobalSetting(DevSettingId id)`:

- Return `false` for settings that do not apply (e.g. Xiaomi `false` for `SpeedStep`, `MinDuty`, `MaxDuty`).
- No changes needed in `button.cpp` or display code besides the dispatcher.

## Xiaomi G ESC UART (implemented)

Hardware: **TX GPIO 17**, **RX GPIO 18**, **9600 8E1**, `HardwareSerial` **Serial2** (see [`motor_xiaomi_g.h`](../motor_xiaomi_g/motor_xiaomi_g.h)).

| File | Role |
|---|---|
| [`xiaomi_g_protocol.h`](../motor_xiaomi_g/xiaomi_g_protocol.h), [`xiaomi_g_protocol.cpp`](../motor_xiaomi_g/xiaomi_g_protocol.cpp) | Checksum, `CTRL` / `SETP` frame builders, stable speeds (150 / 300 / 550), percent→MM |
| [`xiaomi_g_uart.h`](../motor_xiaomi_g/xiaomi_g_uart.h), [`xiaomi_g_uart.cpp`](../motor_xiaomi_g/xiaomi_g_uart.cpp) | `Serial2` begin/end, raw frame TX, optional `0xFE` wake byte |
| [`motor_xiaomi_g.cpp`](../motor_xiaomi_g/motor_xiaomi_g.cpp) | `MotorDriver` hooks: non-blocking ~50 ms / 25 ms CTRL+SETP loop while running; blocking wake (first start) and multi-repeat stop (`CTRL_OFF` + `SETP_STOP`) |

Behavior summary:

- While **motor on**: every cycle sends **CTRL_ON** for current MM, then after **25 ms** **SETP_RUN** with the documented speed for that mode.
- **First start** after init: **0xFE** wake, **25 ms**, then cyclic frames.
- **Stop**: **CTRL_OFF** for current mode, **25 ms**, **SETP_STOP**, repeated **3×** with ~**75 ms** between repeats; driver deinit also sends a single **SETP_STOP**.
- **RX** status frames (`AC 02 …`) are not parsed yet.

## Adding a driver-specific dev-menu row

1. In the driver `.cpp`, add `static uint8_t s_mySetting;` (+ NVS load/save with a **short** key, e.g. `xf_hb_ms`).
2. Define `formatValue`, `formatSubline` (optional), `cycleAndSave`.
3. Build a `DevSettingDescriptor`:

   ```cpp
   { false, DevSettingId::AutoOff /* ignored */, "my_key", "Title",
     fmt, "Static sub", fmtSub, cycle }
   ```

   Use `isGlobal == false`, set `driverKey`, ignore `globalId` for storage naming.

4. Return `MotorDriverSettings{ N, items }` from `driverSettings()`.

Rebuild menu after changing motor type: `devMenuRebuildVisible()` (already called when cycling **Motor Type**).

## Wiring checklist (new motor type)

1. `enum class MotorType` + `clampMotorType` + NVS in [`settings.cpp`](../settings/settings.cpp).
2. `parseMotorType` / `motorTypeToString` / `motorTypeDisplayName`.
3. `motorDriverForType()` in [`motor.cpp`](motor.cpp).
4. Optional: `SettingsConfig::DEFAULT_MOTOR_TYPE`.

## What not to do

- Do not `#include "../motor_foo/motor_foo.h"` outside that folder; use [`motor/motor.h`](motor.h) only.
- Do not call `ledc*` or UART directly from `main` for motor control; keep it in the driver.

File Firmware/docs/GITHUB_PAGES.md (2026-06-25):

# Deploy caznic connect on GitHub Pages

Static hosting for the **hosted** web UI (`Firmware/ui`) at **https://connect.caznic.xyz**.

| Component | Where it runs |
|---|---|
| Web UI (HTTPS) | GitHub Pages |
| Vacuum firmware | ESP32 (WiFi + BLE) |
| BLE link | Browser → vacuum directly |
| WiFi link | **Not available** on GitHub Pages (no server-side WebSocket proxy) |

GitHub Pages serves static files only. The hosted UI shows **Bluetooth only** — WiFi transport is hidden. For WiFi + BLE, run the Node server locally — see [server README](../server/README.md).

## One-time setup

> **Requires repo admin.** If deploy fails with `Failed to create deployment (status: 404)`, Pages is not enabled yet — complete step 1 below as `hkienle` or another administrator.

### 1. Enable GitHub Pages

In the repo on GitHub ([Settings → Pages](https://github.com/hkienle/osh-vacuum/settings/pages)):

1. **Build and deployment** → **Source**: **GitHub Actions** (not “Deploy from a branch”)
2. Save — no branch/path needed when using Actions
3. **Custom domain**: `connect.caznic.xyz` → Save
4. Wait for DNS check, then enable **Enforce HTTPS**

The first successful enable creates the `github-pages` deployment environment. Until this is done, the workflow build succeeds but **deploy** fails with HTTP 404.

The workflow [`.github/workflows/pages.yml`](../../.github/workflows/pages.yml) builds `Firmware/ui` and deploys on every push to `main` that touches the UI (or via **Actions** → **Deploy GitHub Pages** → **Run workflow**).

### 2. DNS (caznic.xyz)

At your DNS provider, add:

| Type | Name | Value |
|---|---|---|
| CNAME | `connect` | `hkienle.github.io` |

If you use Cloudflare, set the record to **DNS only** (grey cloud) until GitHub has issued the TLS certificate.

`Firmware/ui/public/CNAME` is copied into the build output so the custom domain survives each deploy.

### 3. Flash firmware

Flash BLE-capable firmware (`esp32-s3` or `esp32-s3-ble`), then pair from **https://connect.caznic.xyz** in Chrome or Edge.

## Local build (optional)

```bash
cd Firmware/ui
npm install
npm run build:pages
# output in dist/ — same bundle GitHub Pages publishes
```

## Updating

| What changed | Action |
|---|---|
| Web UI only | Merge/push to `main` → workflow redeploys |
| ESP firmware | `pio run -e esp32-s3-ota -t upload` (OTA) or USB flash |

## Troubleshooting

### Deploy job: `Failed to create deployment (status: 404)`

GitHub Pages is **not enabled** on the repository.

1. Open [github.com/hkienle/osh-vacuum/settings/pages](https://github.com/hkienle/osh-vacuum/settings/pages) as a **repo admin**
2. Set **Source** to **GitHub Actions**
3. Re-run the workflow: **Actions** → **Deploy GitHub Pages** → **Run workflow**

### Custom domain not verified

- Confirm CNAME `connect` → `hkienle.github.io`
- Allow up to 24h for DNS propagation
- In **Settings → Pages**, remove and re-add the custom domain if stuck

### Bluetooth unavailable

- Open `https://connect.caznic.xyz` (not `http://`)
- Use Chrome or Edge (Safari has no Web Bluetooth)
- Grant Bluetooth permission when prompted

### WiFi option missing on connect.caznic.xyz

Expected on GitHub Pages. WiFi transport is only shown when self-hosting (e.g. `http://localhost:8080` with `Firmware/server`). Use BLE on the public site, or run the server locally for WiFi.

## Related docs

- [Hosted UI + BLE architecture](./HOSTED_UI_BLE.md)
- [Hosted server README](../server/README.md) (local dev + optional self-hosted WiFi proxy)

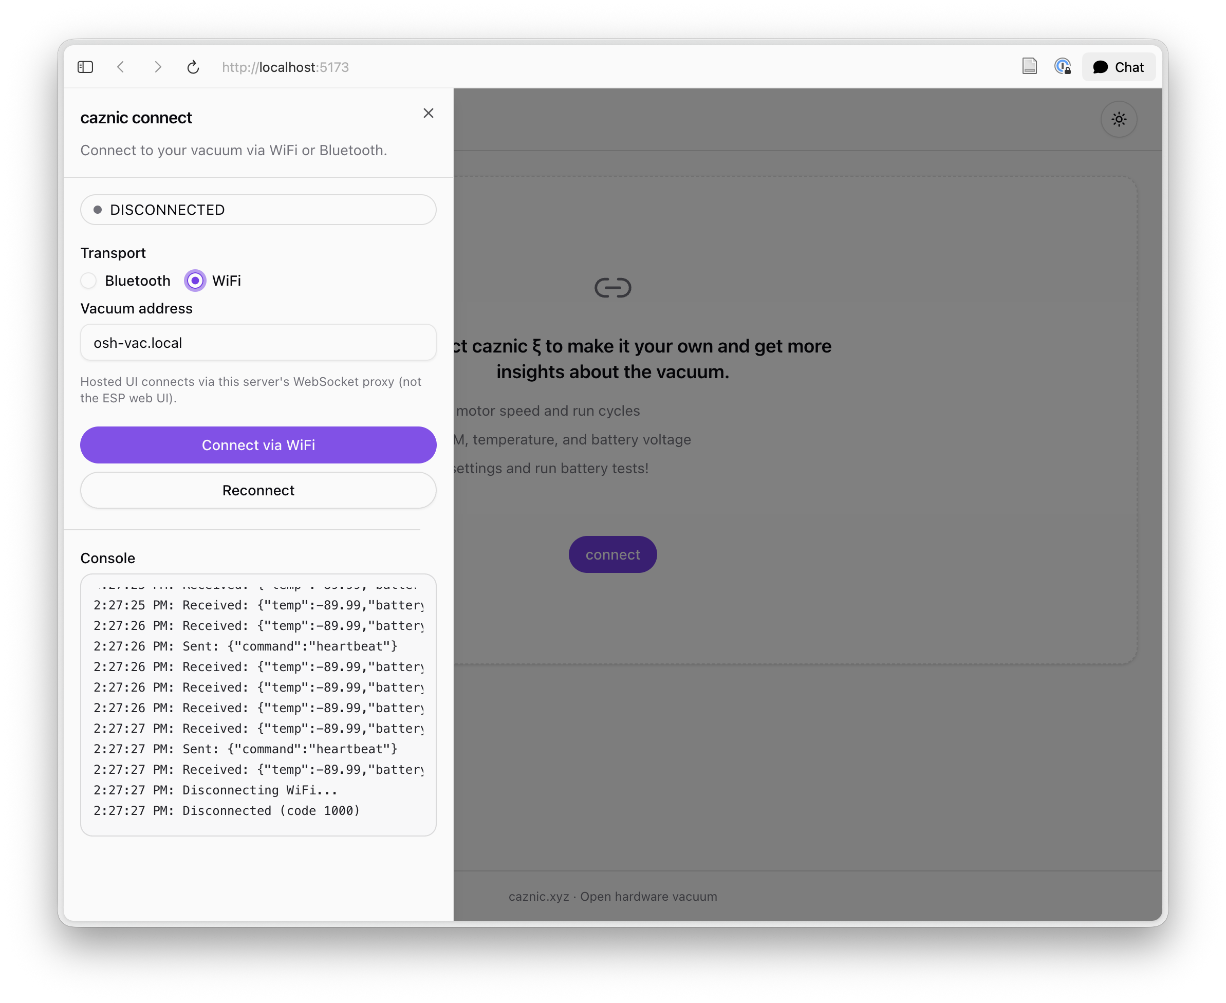
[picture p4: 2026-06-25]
Firmware/ui/public/onboarding/connection.png

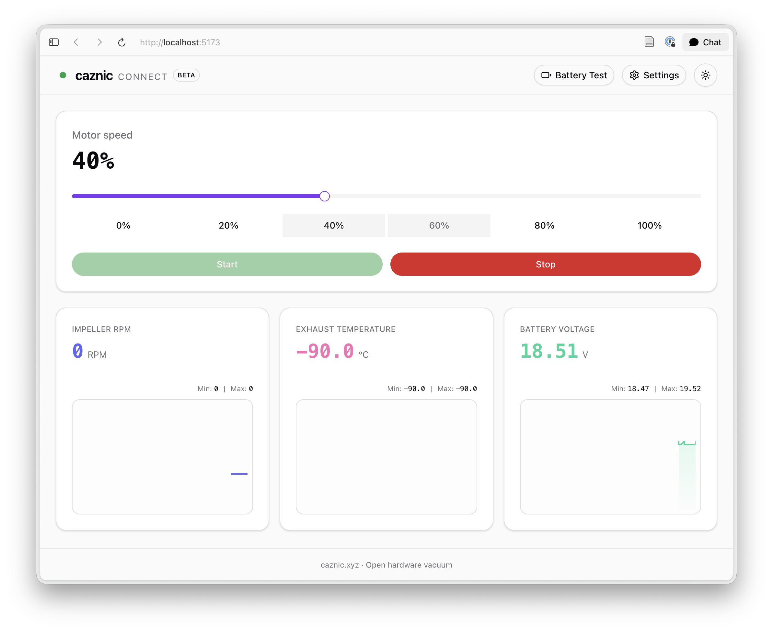
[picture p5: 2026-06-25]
Firmware/ui/public/onboarding/control.png

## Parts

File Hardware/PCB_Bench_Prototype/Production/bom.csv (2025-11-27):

Designator | Footprint | Quantity | Value | LCSC Part #
C1, C7, C8, C9 | 0805 | 4 | 22uF
C10, C11, C12, C13, C14, C2, C5 | 0805 | 7 | 0.1uF
C3 | 0805 | 1 | 1uF
C4 | 0805 | 1 | 10nF
C6 | 0805 | 1 | 10uF
J1, J2, J3, J4 | SolderWirePad_1x01_SMD_5x10mm | 4 | Conn_01x01_Pin
J5 | PinHeader_2x05_P2.54mm_Vertical | 1 | Conn_01x10
J6 | PinHeader_1x02_P2.54mm_Vertical | 1 | Conn_01x02_Pin
LED1, LED2, LED3, LED4, LED5 | LED-SMD_4P-L5.0-W5.0-TL-1 | 5 | WS2812B-V5/W | C2874885
P1, P2 | CONN-TH_2P-P5.00_WJ301V-5.00-2P | 2 | WJ301V-5.0-2P | C8475
R10 | 0805 | 1 | 330k
R11 | 0805 | 1 | 33k
R12 | 0805 | 1 | 56k
R13 | 0805 | 1 | 4.7k
R14, R16 | 0805 | 2 | 5.1k
R15, R17, R18, R3, R5, R6, R7, R8 | 0805 | 8 | 10k
R4 | 0805 | 1 | 220R
R9 | 0805 | 1 | 22k
SW1, SW2 | SW-SMD_4P-L4.2-W3.2-P2.15-LS4.6 | 2 | RKB2SJK250SMTRLFS | C2927789
SW6, SW7, SW8 | KEY-SMD_4P-L5.2-W5.2-P3.7-LS6.4-TL | 3 | TS-1076S-A7B3 | C492950
TP1, TP10, TP11, TP2, TP20, TP21, TP22, TP23, TP24, TP25, TP26, TP27, TP3, TP4, TP5, TP6, TP7, TP8, TP9 | TestPoint_Pad_D1.0mm | 19 | TestPoint
U1 | WIRELM-SMD_ESP32-S3-WROOM-1 | 1 | ESP32-S3-WROOM-1(N16R2) | C2913205
U2 | PG-HSOF-8_L10.4-W9.8-BTH500151LUAAUMA1 | 1 | BTH500151LUAAUMA1 | C36571656
U3 | SOT-223-4_L6.5-W3.5-P2.30-LS7.0-BR | 1 | LD1117S33CTR | C35879
U4, U5 | SC-70-5_L2.0-W1.3-P0.65-LS2.1-BL | 2 | SN74AHCT1G125DCKR | C350557
U8 | PWRM-TH_L11.7-W7.5_TSR1-2450 | 1 | TSR 1-2450_C6886877 | C6886877
U9 | USB-SMD_TYPE-C16PIN-1 | 1 | 12402012E212A | C5150972

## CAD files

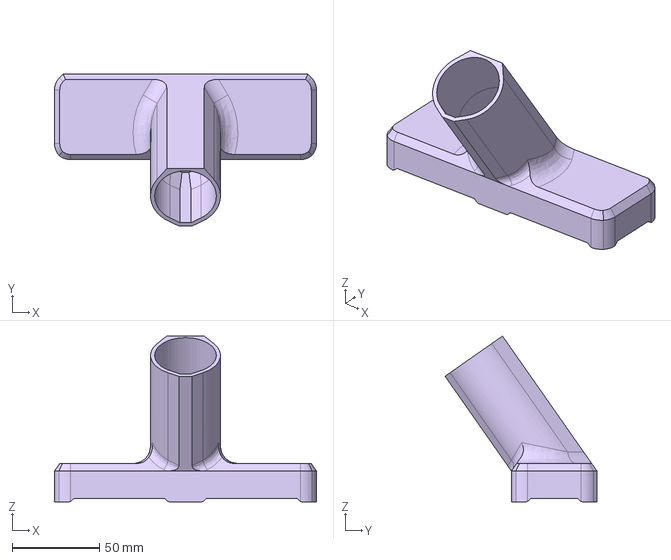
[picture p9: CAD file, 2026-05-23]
Hardware/VAC_Printed_Parts/Aux/Nozzle/OSH_Vac_nozzle-flat-d35-w150_v1.step
150.0 x 87.0 x 95.0 mm

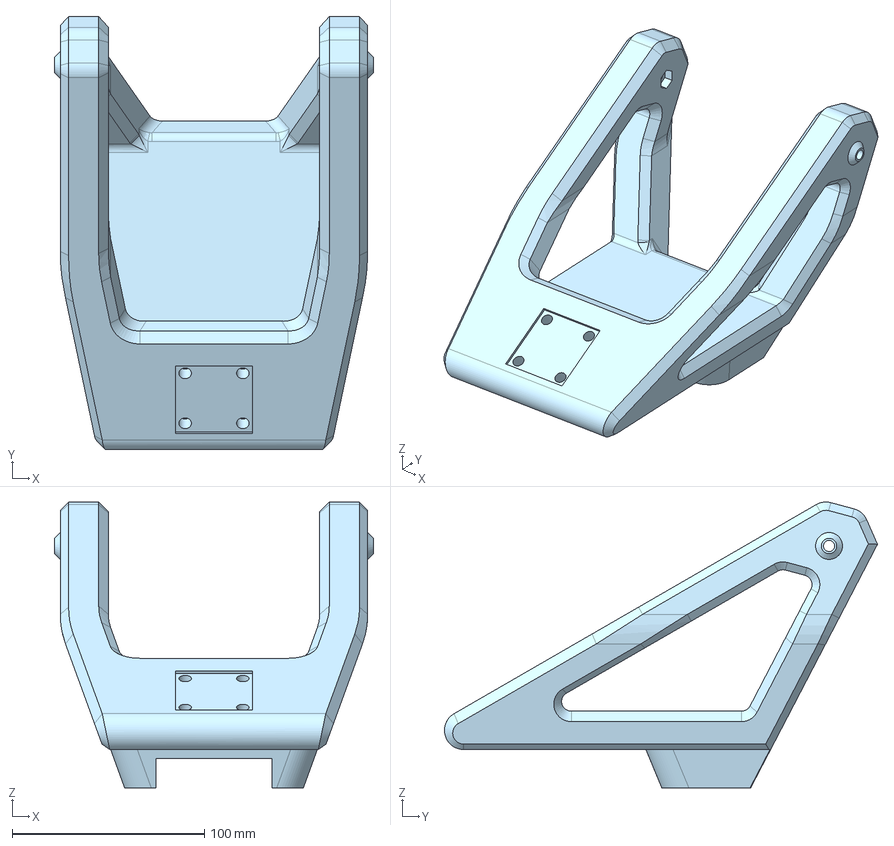
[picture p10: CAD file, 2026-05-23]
Hardware/VAC_Printed_Parts/Aux/OSH_Vac_cart_v1.step
166.0 x 225.3 x 148.8 mm

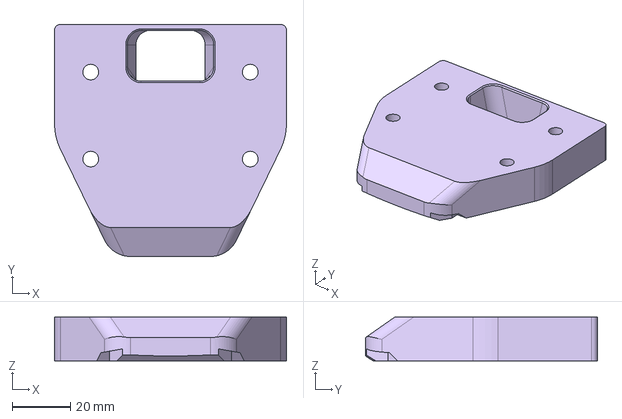
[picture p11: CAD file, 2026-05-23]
Hardware/VAC_Printed_Parts/Core/BatteryAdapter/OSH_Vac_core-batteryadapter-parkside_20v-base_v1.step
80.0 x 80.0 x 15.0 mm

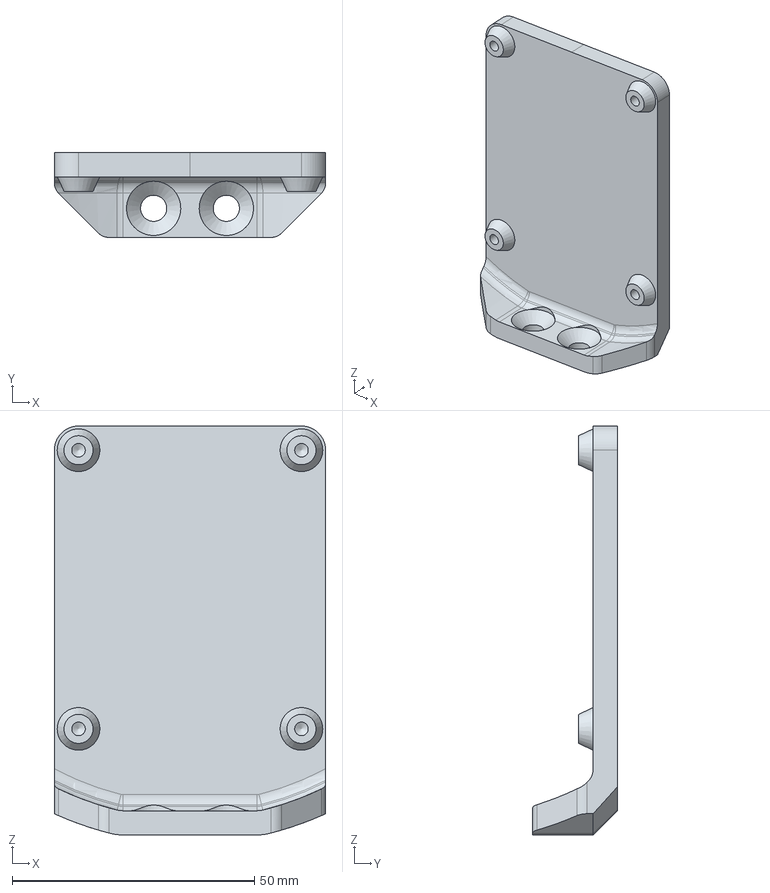
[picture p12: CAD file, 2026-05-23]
Hardware/VAC_Printed_Parts/Core/OSH_Vac_core-pcbmount_v1.step
56.0 x 17.5 x 84.4 mm

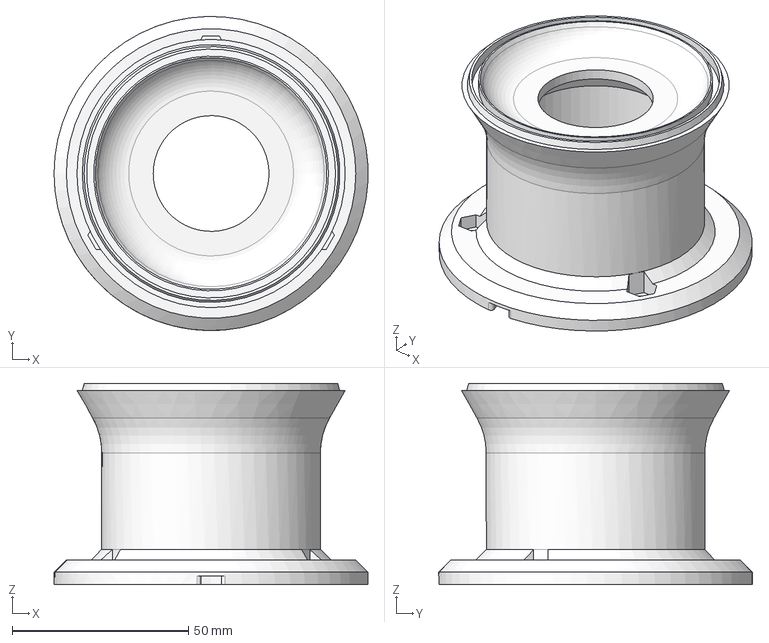
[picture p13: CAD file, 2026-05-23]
Hardware/VAC_Printed_Parts/Dustbin/Cyclone/OSH_Vac_dustbin-cyclone-bottom_v1.1.step
88.9 x 89.0 x 57.0 mm

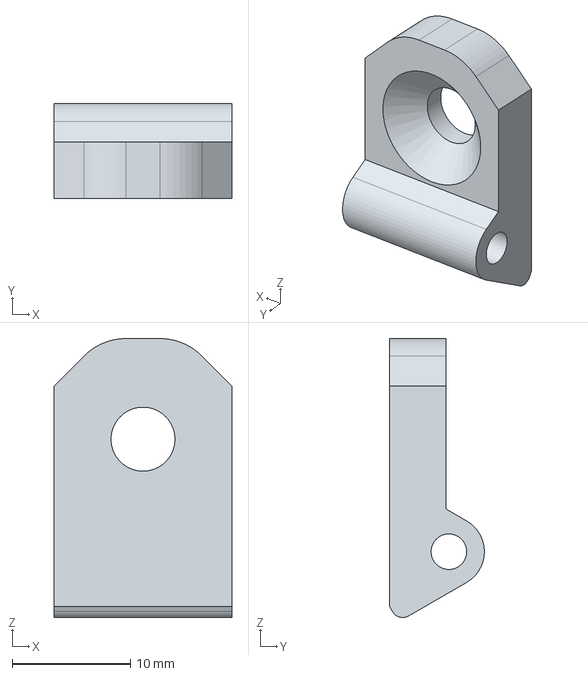
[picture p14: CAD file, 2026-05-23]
Hardware/VAC_Printed_Parts/Dustbin/OSH_Vac_dustbin-hinge-latch_v1.step
15.0 x 7.99 x 23.6 mm

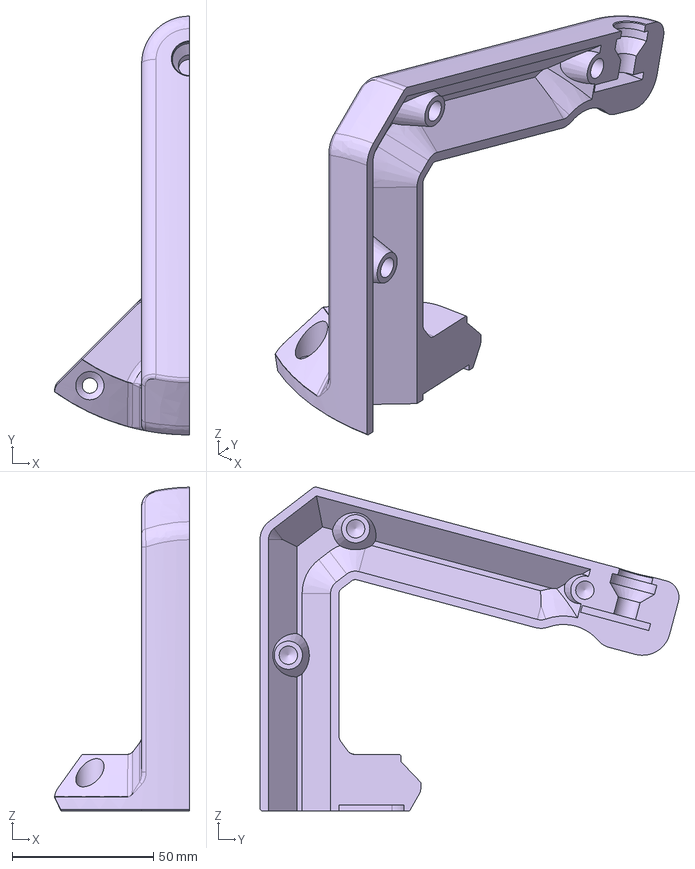
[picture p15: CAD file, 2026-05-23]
Hardware/VAC_Printed_Parts/Lid/Handle/BackHandle/OSH_Vac_lid-insert-backhandle-left_v1.step
47.9 x 148.4 x 114.6 mm

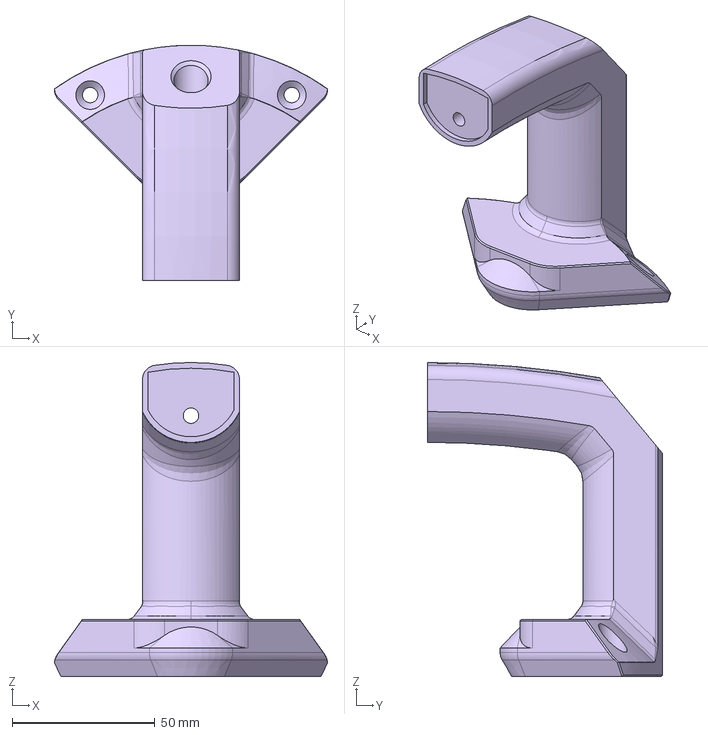
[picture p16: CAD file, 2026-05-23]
Hardware/VAC_Printed_Parts/Lid/Handle/BucketHandle/OSH_Vac_lid-insert-buckethandle-left_v1.step
95.8 x 82.5 x 110.0 mm

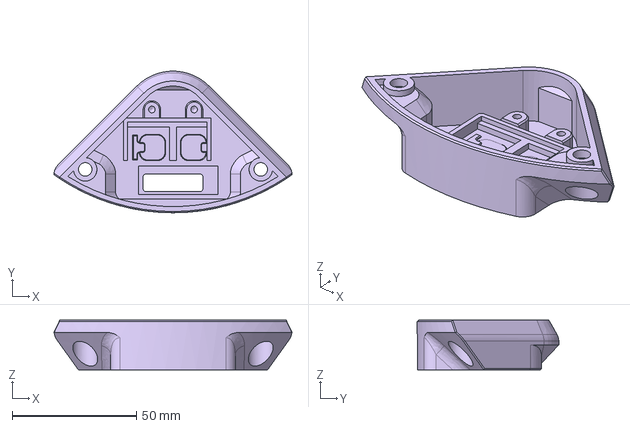
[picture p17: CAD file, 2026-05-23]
Hardware/VAC_Printed_Parts/Lid/HMI/OSH_Vac_lid-insert-hmi_v1.step
95.8 x 57.0 x 20.0 mm

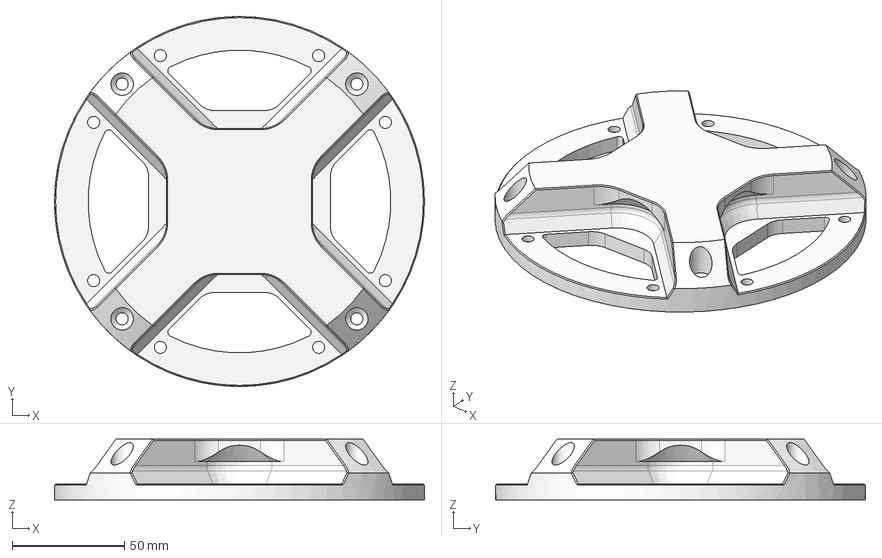
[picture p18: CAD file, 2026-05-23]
Hardware/VAC_Printed_Parts/Lid/OSH_Vac_lid_v1.step
165.0 x 165.0 x 27.0 mm

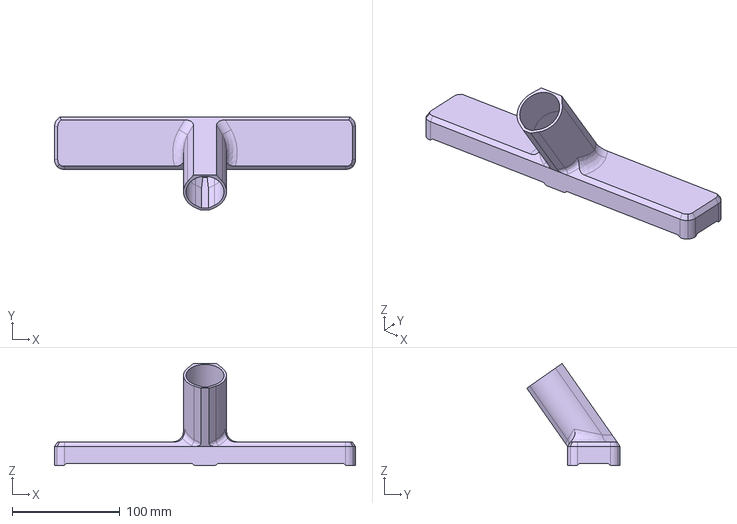
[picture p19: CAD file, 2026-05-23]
Hardware/VAC_Printed_Parts/Aux/Nozzle/OSH_Vac_nozzle-flat-d35-w280_v1.step
280.0 x 87.0 x 95.0 mm

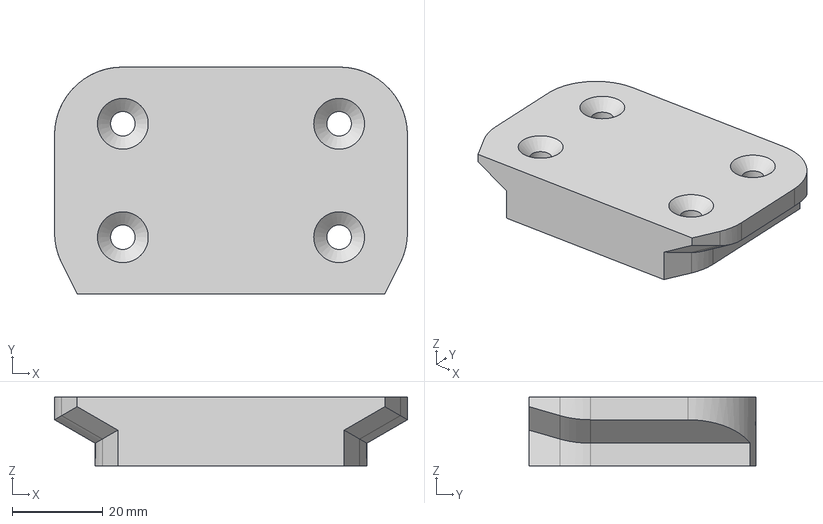
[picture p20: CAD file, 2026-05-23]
Hardware/VAC_Printed_Parts/Aux/OSH_Vac_wallmount_v1.step
77.8 x 50.0 x 15.2 mm

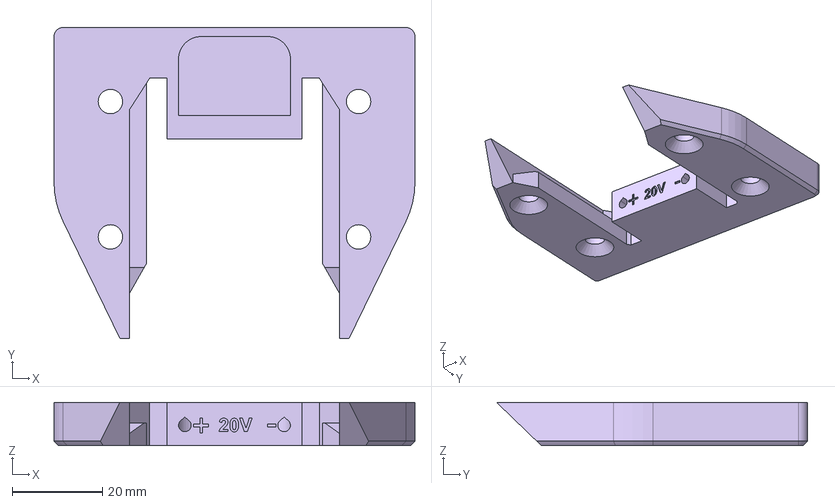
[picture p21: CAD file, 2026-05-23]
Hardware/VAC_Printed_Parts/Core/BatteryAdapter/OSH_Vac_core-batteryadapter-parkside_20v-slot_v1.step
80.0 x 68.9 x 9.60 mm

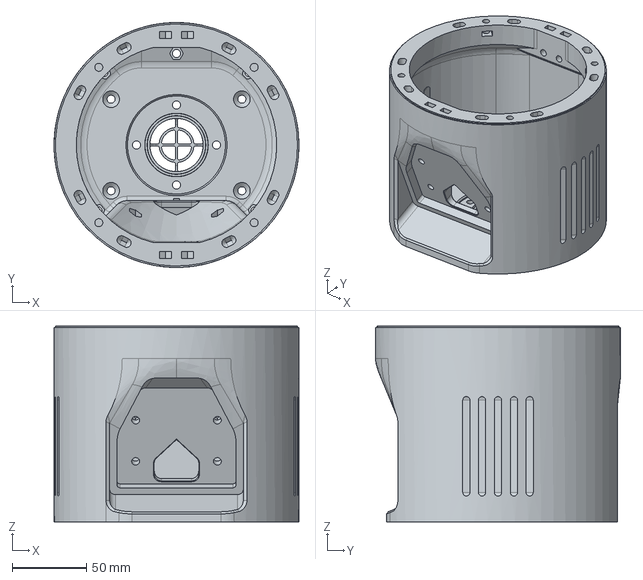
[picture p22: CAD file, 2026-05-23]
Hardware/VAC_Printed_Parts/Core/OSH_Vac_core_v1.2.step
165.0 x 165.0 x 132.0 mm

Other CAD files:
Hardware/VAC_Printed_Parts/Dustbin/Cyclone/OSH_Vac_dustbin-cyclone-mesh_v1.step
Hardware/VAC_Printed_Parts/Dustbin/OSH_Vac_dustbin-stickadapter-xiaomi_v1.step
Hardware/VAC_Printed_Parts/Lid/Handle/BackHandle/OSH_Vac_lid-insert-handle-button_v1.step
Hardware/VAC_Printed_Parts/Lid/Handle/BucketHandle/OSH_Vac_lid-insert-buckethandle-right_v1.step
Hardware/VAC_Printed_Parts/Aux/Nozzle/OSH_Vac_nozzle-flat-d32-w100_v1.step
Hardware/VAC_Printed_Parts/Aux/Nozzle/OSH_Vac_nozzle-flat-d32-w150_v1.step
Hardware/VAC_Printed_Parts/Aux/Nozzle/OSH_Vac_nozzle-flat-d32-w200_v1.step
Hardware/VAC_Printed_Parts/Aux/Nozzle/OSH_Vac_nozzle-flat-d32-w280_v1.step
Hardware/VAC_Printed_Parts/Aux/Nozzle/OSH_Vac_nozzle-flat-d35-w100_v1.step
Hardware/VAC_Printed_Parts/Aux/Nozzle/OSH_Vac_nozzle-flat-d35-w200_v1.step
Hardware/VAC_Printed_Parts/Aux/Nozzle/OSH_Vac_nozzle-flat-d40-w100_v1.step
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

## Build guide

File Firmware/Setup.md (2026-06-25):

# OSH Vacuum — Setup Guide

Everything you need to configure, build, and flash the firmware. For an overview of what the firmware does, see [README.md](README.md).

---

## Prerequisites

- [PlatformIO](https://platformio.org/) — CLI (`pip install platformio`) or the PlatformIO IDE extension for VS Code / Cursor.
- USB-C cable with data support (not charge-only).
- Node.js ≥ 18 + npm (for the frontend build, first time only).

---

## Step 1 — Create your local config file

`settings_config.h` holds your WiFi credentials, device hostname, and OTA password. It is gitignored and must be created locally from the example:

```bash
cp Firmware/src/settings/settings_config.example.h \
   Firmware/src/settings/settings_config.h
```

Open `settings_config.h` and set your values:

```cpp
// Your home/lab network
constexpr char WIFI_STA_SSID[]     = "YourNetworkName";
constexpr char WIFI_STA_PASSWORD[] = "YourNetworkPassword";

// Fallback hotspot (used when STA fails)
// SSID is always DEVICE_HOSTNAME
constexpr char WIFI_AP_PASSWORD[]  = "YourAPPassword";

// Device identity — used for mDNS and OTA
constexpr char DEVICE_HOSTNAME[]   = "osh-vac";
constexpr char OTA_HTTP_PASSWORD[] = "YourOTAPassword";
```

All other constants in that file are compile-time defaults for runtime settings (display type, battery cells, speed step, etc.). They take effect on first boot or when the NVS entry is missing. See [Usage Guide](usage.md) for a full description of each setting.

---

## Step 2 — Align platformio.ini with your config

For wireless OTA uploads to work, `platformio.ini` must match your `settings_config.h`:

```ini
[env:esp32-s3-ota]
upload_port  = osh-vac.local    ; must match DEVICE_HOSTNAME
upload_flags =
    --auth=YourOTAPassword      ; must match OTA_HTTP_PASSWORD
```

The USB environment (`esp32-s3`) needs no changes.

---

## Step 3 — Build the frontend

The web interface is a React + TypeScript app. Build it once before the first flash, and again whenever you change the UI.

```bash
cd Firmware/ui
npm install           # first time only
npm run build:esp32   # outputs to Firmware/data/
```

For local UI development with hot-reload (connects to a live device):

```bash
npm run dev           # typically http://localhost:5173
```

---

## Step 4 — First-time flash via USB

Connect the board via USB-C, then from the `Firmware/` directory:

```bash
# 1. Upload the firmware binary
pio run -e esp32-s3 -t upload

# 2. Upload the web UI (LittleFS filesystem)
pio run -e esp32-s3 -t uploadfs
```

> If the device doesn't enter flash mode automatically: hold **BOOT**, press **RESET**, release **BOOT**, then retry.

After flashing, open the serial monitor to verify the boot:

```bash
pio device monitor    # 115200 baud
```

Look for a `[BOOT]` line — it shows the WiFi mode and IP address:

```
[BOOT] Mode=STA IP=192.168.1.42 Hostname=osh-vac
```

---

## Wireless updates (OTA)

Once the device is on the network, you can update the firmware without USB:

```bash
cd Firmware
pio run -e esp32-s3-ota -t upload
```

If mDNS resolution of `<hostname>.local` is unreliable, pass the IP directly:

```bash
pio run -e esp32-s3-ota -t upload --upload-port 192.168.1.42
```

The device shows an OTA progress bar on the OLED and reboots automatically on success.

## Web Settings Modal

The web UI now includes a **Settings** modal that mirrors all on-device dev-menu runtime settings.
Changes apply immediately and are persisted through the existing WebSocket channel.

WebSocket settings protocol:

- `{"command":"get_settings"}` -> returns `{"settings": {...}, "schema": {...}, "motor_type": <n>}`
- `{"command":"set_setting","key":"<nvs_key>","value":<number>}` -> applies, persists, and replies with `{"ack":"set_setting","key":"...","ok":true|false}`
- Any successful change also triggers a broadcast payload with updated `settings` + `schema`

> **Three values must always be in sync:**
> 
> | File | Key |
> |------|-----|
> | `settings_config.h` | `DEVICE_HOSTNAME` → ArduinoOTA hostname + mDNS name |
> | `settings_config.h` | `OTA_HTTP_PASSWORD` → ArduinoOTA password |
> | `platformio.ini` `[env:esp32-s3-ota]` | `upload_port` = `<DEVICE_HOSTNAME>.local` (or IP) |
> | `platformio.ini` `[env:esp32-s3-ota]` | `upload_flags` = `--auth=<OTA_HTTP_PASSWORD>` |

---

## Configuration reference

### Compile-time defaults (`settings_config.h`)

These apply on first boot or whenever the corresponding NVS entry is absent. All of them can be overridden at runtime via the on-device settings menu.

| Constant | Default | Description |
|---|---|---|
| `DEFAULT_DISPLAY_TYPE` | `"0.91-I2C-Waveshare"` | Display backend (`"0.91-I2C-Waveshare"`, `"1.5-I2C-Waveshare"`, `"none"`) |
| `DEFAULT_BATTERY_SERIES_CELLS` | `5` | Series cell count for SOC calculation |
| `DEFAULT_AUTO_OFF_MINUTES` | `2` | Motor auto-off timeout in minutes (0 = disabled) |
| `DEFAULT_SLEEP_TIMER_MINUTES` | `2` | Inactivity sleep timeout in minutes (0 = disabled) |
| `DEFAULT_TEMP_LIMIT_C` | `0` | NTC motor cutoff in °C (0 = disabled) |
| `DEFAULT_SPEED_STEP_PERCENT` | `20` | UP/DOWN button speed step |
| `DEFAULT_MIN_DUTY_PERCENT` | `0` | Minimum PWM duty floor when motor runs |
| `DEFAULT_MOTOR_DISPLAY_MODE` | `2` (RPM) | Main display value: 0=Speed%, 1=Voltage, 2=RPM, 3=Motor Temp |
| `DEFAULT_TRIGGER_MODE` | `0` (Hold) | Trigger behaviour: 0=Hold, 1=Double-Press |

### Runtime NVS keys (`oshvac` namespace)

All values can be changed via the on-device settings menu (pages 5–12) and persist across reboots.

| NVS Key | Allowed Values | Description |
|---|---|---|
| `display_type` | `0.91-I2C-Waveshare`, `1.5-I2C-Waveshare`, `none` | Active display backend |
| `bat_cells` | 1–14 (UI) / 1–32 (NVS) | Battery series cell count |
| `auto_off` | 0, 1, 2, 5, 10, 30 | Motor auto-off in minutes |
| `temp_lim` | 0, 30–70 (step 5 °C) | NTC cutoff temperature |
| `spd_step` | 1, 5, 10, 20, 25 | Speed step % |
| `min_duty` | 1–30 | Minimum PWM duty % |
| `mtr_disp` | 0–3 | Motor-on display value |
| `sleep_tmr` | 1, 2, 5, 10, 30 | Inactivity sleep timer in minutes |
| `trig_mode` | 0=Hold, 1=Double-Press | Trigger behaviour |

---

## Calibration

| What | Where |
|---|---|
| Battery voltage (two-point linear) | `battery/battery.cpp` — `CAL_VTRUE1/2`, `CAL_VMEAS1/2` |
| Battery SOC OCV curve | `battery_soc/battery_soc.cpp` — per-cell voltage breakpoints |
| NTC R0 / Beta / series resistor | `temperature/temperature.cpp` |
| Pulses per revolution | `tachometer/tachometer.cpp` — `PULSES_PER_REV` |

---

## Troubleshooting

**USB upload fails**
- Use a USB-C cable that supports data.
- Hold **BOOT**, press **RESET**, release **BOOT**, then retry upload.
- Run `pio device list` to confirm PlatformIO sees the port.

**OTA upload fails**
- Verify the device is online: check the `[BOOT]` IP in the serial log or the display.
- Confirm `DEVICE_HOSTNAME` / `OTA_HTTP_PASSWORD` in `settings_config.h` match `upload_port` / `--auth` in `platformio.ini`.
- Try `--upload-port <ip>` if mDNS (`*.local`) doesn't resolve.
- If credentials are wrong, recover via USB: `pio run -e esp32-s3 -t upload`.

**Web UI not loading**
- Check that the filesystem was uploaded: `pio run -e esp32-s3 -t uploadfs`.
- Check serial output for LittleFS mount errors at boot.
- Ensure `Firmware/data/` has the built assets (`npm run build:esp32`).

**Display not initialising**
- Serial prefixes: `OLED:` (0.91"), `1.5OLED:` (1.5"). Look for I2C ACK errors.
- For the 1.5" Waveshare module: it ships in SPI mode and requires hardware I2C configuration via BS1/BS2 strapping (see Waveshare documentation).

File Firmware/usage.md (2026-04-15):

# OSH Vacuum — Usage Guide

Step-by-step guide for operating the device, reading status info, and changing settings. For build and flash instructions → [Setup.md](Setup.md).

---

## Powering on

After power-on, the device attempts to connect to the configured WiFi network:

- **Connection successful** → LEDs turn **solid blue**, display shows the main screen.
- **Connection failed** → Device starts its own **hotspot** (LEDs turn **solid orange**).

The serial log (115200 baud) prints a `[BOOT]` line with mode and IP — useful without a display:

```
[BOOT] Mode=STA IP=192.168.1.42 Hostname=osh-vac
```

---

## Buttons

| Button | Function |
|---|---|
| **TRIGGER** | Start / stop motor (behaviour depends on trigger mode) |
| **UP** | Increase speed |
| **DOWN** | Decrease speed |
| **UP + DOWN** held ≥ 1.5 s | Open / close the dev menu |

---

## Running the motor

The device supports two trigger modes. The active mode is shown on page 12 of the dev menu.

### Mode 1: Hold (default)

| Action | Result |
|---|---|
| Hold TRIGGER ≥ 1.25 s | Motor starts |
| Press TRIGGER briefly (motor running) | Motor stops |

### Mode 2: Double-Press

| Action | Result |
|---|---|
| Press and hold TRIGGER | Motor runs while held — stops on release (momentary) |
| Tap TRIGGER twice quickly (< 300 ms apart) | Motor latches ON |
| Press TRIGGER (while latched) | Motor stops |

---

## Setting the speed

- **UP** / **DOWN** adjust the speed in configurable steps (default: 20%).
- With 20% steps the levels are: 0% → 20% → 40% → 60% → 80% → 100%.
- The speed setpoint is preserved after a motor stop and after waking from sleep.
- The **web interface** allows continuous speed control (0–100%).

---

## LEDs

| State | LEDs |
|---|---|
| Booting / connecting to WiFi | Pulsing white |
| WiFi connected (router) | Solid blue |
| Hotspot mode | Solid orange |
| Motor off, speed = 0% | 1 LED pulsing slowly (blue) |
| Motor off, speed > 0% | Speed bar — blue (1 LED ≈ 20%) |
| Motor active | Speed bar — red |

---

## Display — main screen

| Element | Description |
|---|---|
| **Speed bar** | Current speed setpoint (0–100%) as a horizontal bar |
| **Top line** | Configurable: Speed %, pack voltage (V), RPM, or motor temperature (°C) — set on page 10 of the dev menu |
| **Battery icon** | State of charge in % — shows `--` while the motor is running |

**Battery icon fill:**

| SOC | Display |
|-----|---|
| 80–100% | All bars filled |
| 30–80% | Two bars |
| 15–30% | One bar |
| 0–15% | One bar blinking |
| Motor running | `--` |

---

## Dev menu — status & settings

**Open:** hold UP + DOWN simultaneously for ≥ 1.5 seconds.  
**Navigate:** UP / DOWN cycle through 13 pages.  
**Change a setting (pages 5–12):** press TRIGGER to step through the allowed values — saved to NVS immediately.  
**Close:** hold UP + DOWN again for ≥ 1.5 seconds (release both buttons first, then hold again).

> The motor does not run while the dev menu is open.

### Status pages (read-only)

| Page | Shows |
|---|---|
| 0 | Battery: series cell count, SOC %, pack voltage |
| 1 | WiFi: mode (STA/AP), IP address, SSID |
| 2 | WiFi: hostname, signal strength (RSSI) |
| 3 | System: uptime, free heap |
| 4 | Additional system info |

### Settings pages (press TRIGGER to change)

| Page | Setting | Allowed values |
|---|---|---|
| 5 | **Motor auto-off** — stops the motor after X minutes of continuous run | 0 (off), 1, 2, 5, 10, 30 min |
| 6 | **Temperature limit** — motor stops if NTC exceeds this value | 0 (off), 30–70 °C (step 5 °C) |
| 7 | **Speed step** — how many % each UP/DOWN press changes | 1, 5, 10, 20, 25% |
| 8 | **Minimum PWM duty** — PWM floor when motor is running | 1–30% |
| 9 | **Battery series cells** — cell count for SOC calculation | 1–14 |
| 10 | **Top-line display value** — what the main screen shows while motor runs | Speed%, Voltage (V), RPM, Motor Temp (°C) |
| 11 | **Sleep timer** — inactivity timeout before entering light sleep | 1, 2, 5, 10, 30 min |
| 12 | **Trigger mode** | Hold, Double-Press |

---

## WiFi & web interface

### Finding the device IP

- **Display:** dev menu → page 1 shows IP address and SSID.
- **Serial:** `[BOOT]` line after startup (USB-serial, 115200 baud).

### Opening the web interface

- **By IP:** `http://192.168.1.42` (port 80; use the IP from above).
- **By hostname:** `http://osh-vac.local` (if mDNS works on your network; hostname visible on page 2 of the dev menu).
- **In hotspot mode:** connect to the `OSH_VAC` network first, then typically `http://192.168.4.1`.

The web interface shows live sensor data (temperature, voltage, RPM, speed) and allows motor control and speed adjustment.

---

## Auto-sleep

The device enters **light sleep** automatically when all of the following are true for the configured sleep timer duration (default: 2 minutes):
- No button activity
- Motor not running
- No OTA update in progress

Before sleeping: motor stopped, LEDs off, display off.  
**Wake:** press any button. The speed setpoint is preserved.

Setting the sleep timer to 0 (page 11) disables auto-sleep entirely.

---

## Safety features

| Feature | Setting | Behaviour |
|---|---|---|
| **Auto-off** | Page 5 — Motor auto-off | Motor stops after X minutes of continuous run |
| **Temperature limit** | Page 6 — Temperature limit | Motor stops when NTC temperature ≥ limit |
| **Minimum PWM** | Page 8 — Minimum PWM duty | Prevents motor stall at low speed settings |

---

## Safety notes

- High RPM and moving parts: only operate the device with proper guarding and per the manufacturer's specifications.
- Battery: avoid short circuits and reverse polarity; use appropriate cell chemistry and protection circuits.
- OTA and credentials: replace the default passwords in any network accessible to others.

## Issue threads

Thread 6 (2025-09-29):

Leverage spare parts of commercial vacuums

hkienle, 2025-09-29:
We may want to consider to use spare/replacement parts of commercial vacuum cleaners in our design. I am not sure whether this should be our preferred route in the design though.

Pro:
- Replacement parts tend to be reasonably cheap on AliExpress. (Unfortunately, spare parts in Germany seem prohibitively expensive.)

Considerations:
- Use adapters in the design to have more flexibility in using different replacement parts.

## Examples

### G20 HEPA filter #4

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

https://de.aliexpress.com/item/1005009353234175.html

###  robot vacuums

- Brushes, filters, wheel assemblies, dust bags
- https://de.aliexpress.com/w/wholesale-robot-vaccum-spare-parts.html

hkienle, 2025-10-06:
> create a document

Maybe add to _Design Constraints/Considerations_: https://hackmd.io/lt3Uhc9NQEG3cFUj-SkzNg

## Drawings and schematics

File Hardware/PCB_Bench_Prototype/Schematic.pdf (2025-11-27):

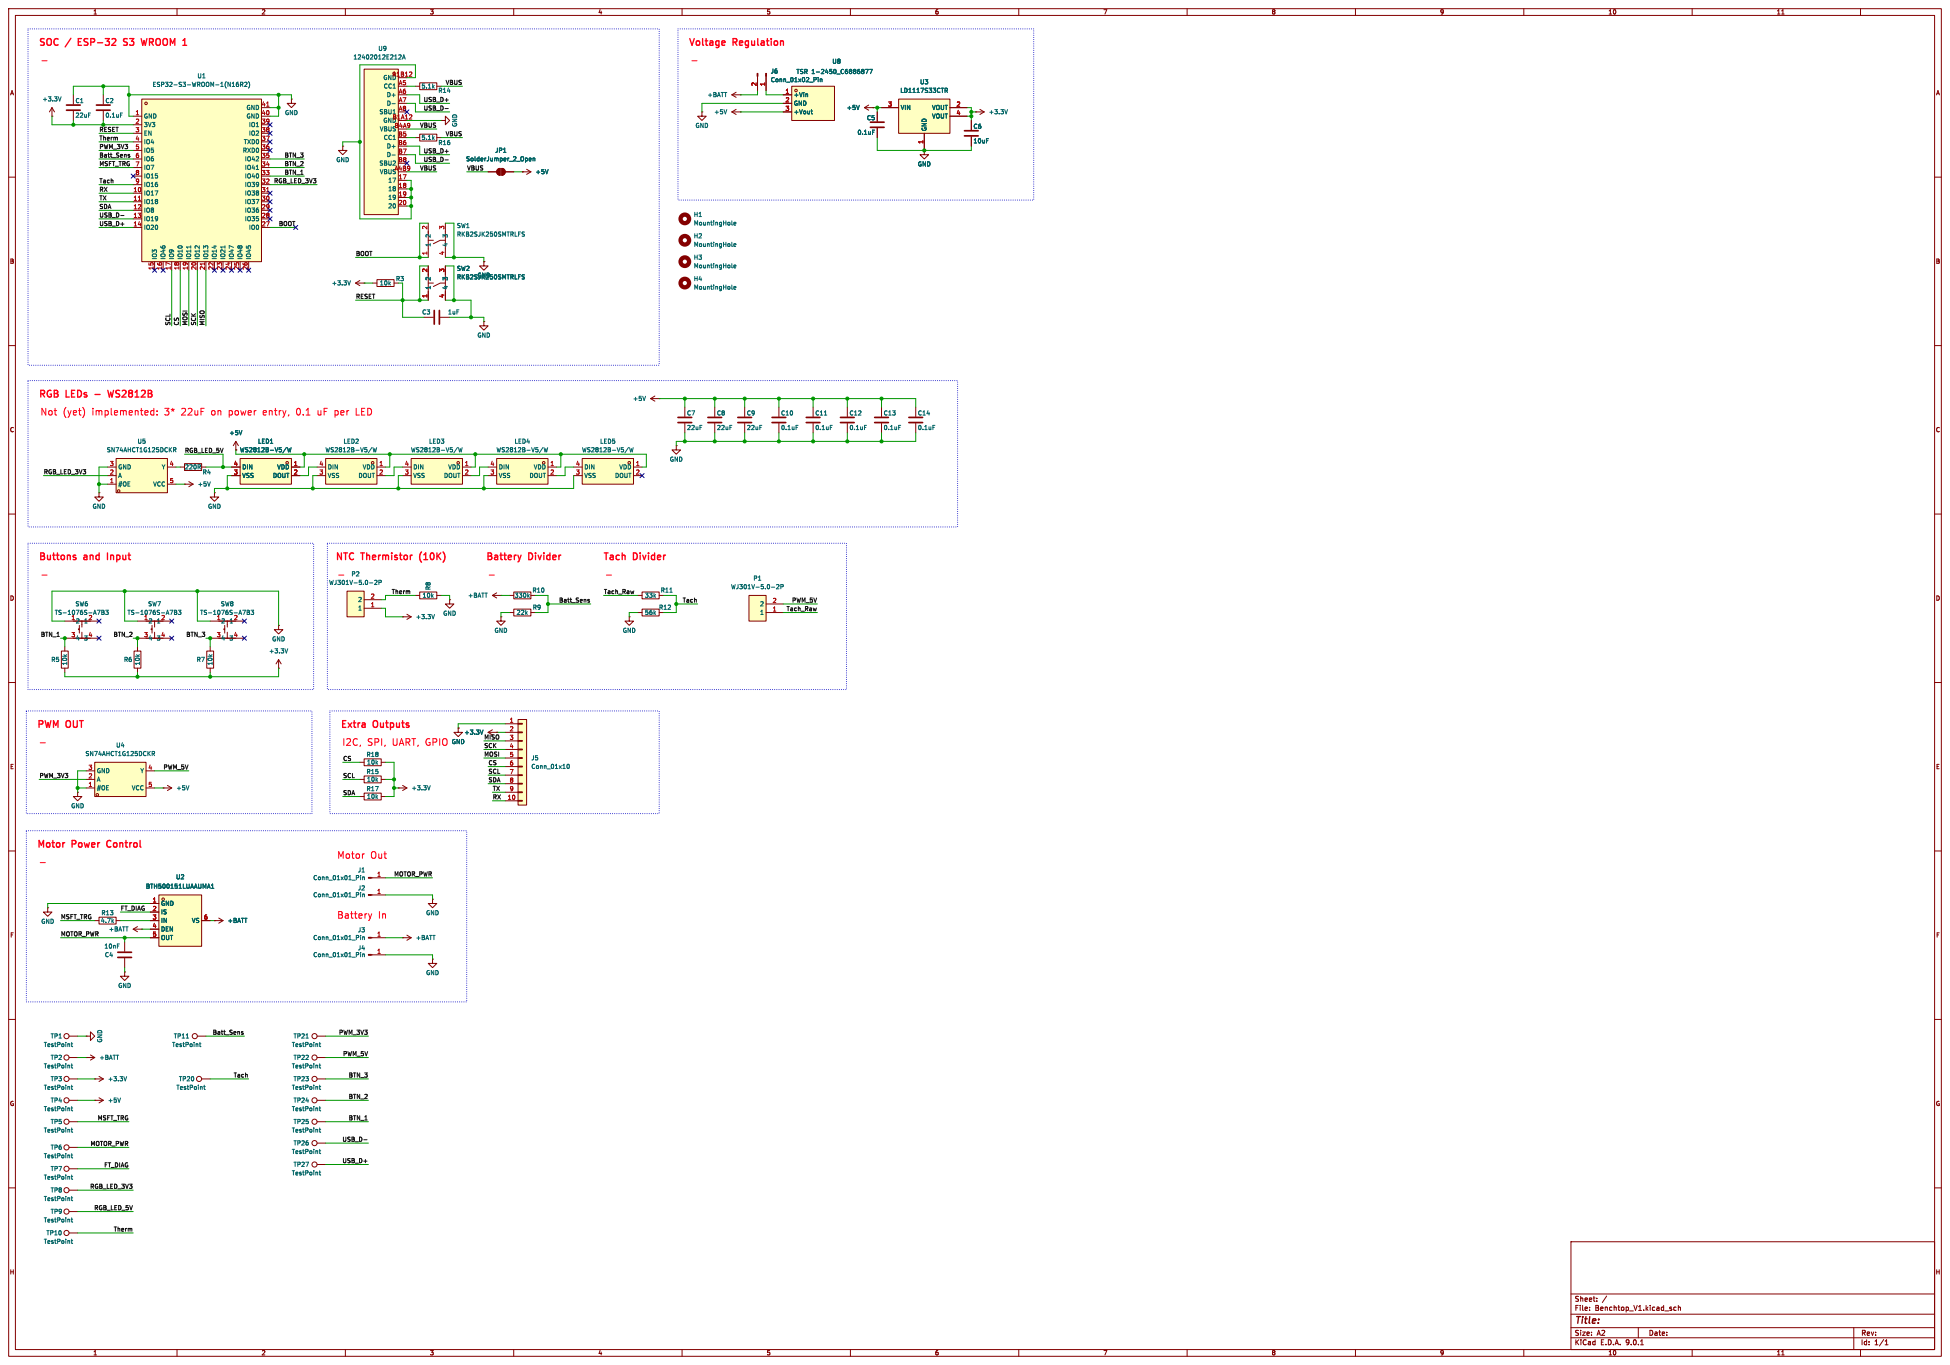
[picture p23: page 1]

VDD 1 DOUT 2 DIN 4 VSS 3 +5V
LED1 WS2812B-V5/W

VDD 1 DOUT 2 DIN 4 VSS 3

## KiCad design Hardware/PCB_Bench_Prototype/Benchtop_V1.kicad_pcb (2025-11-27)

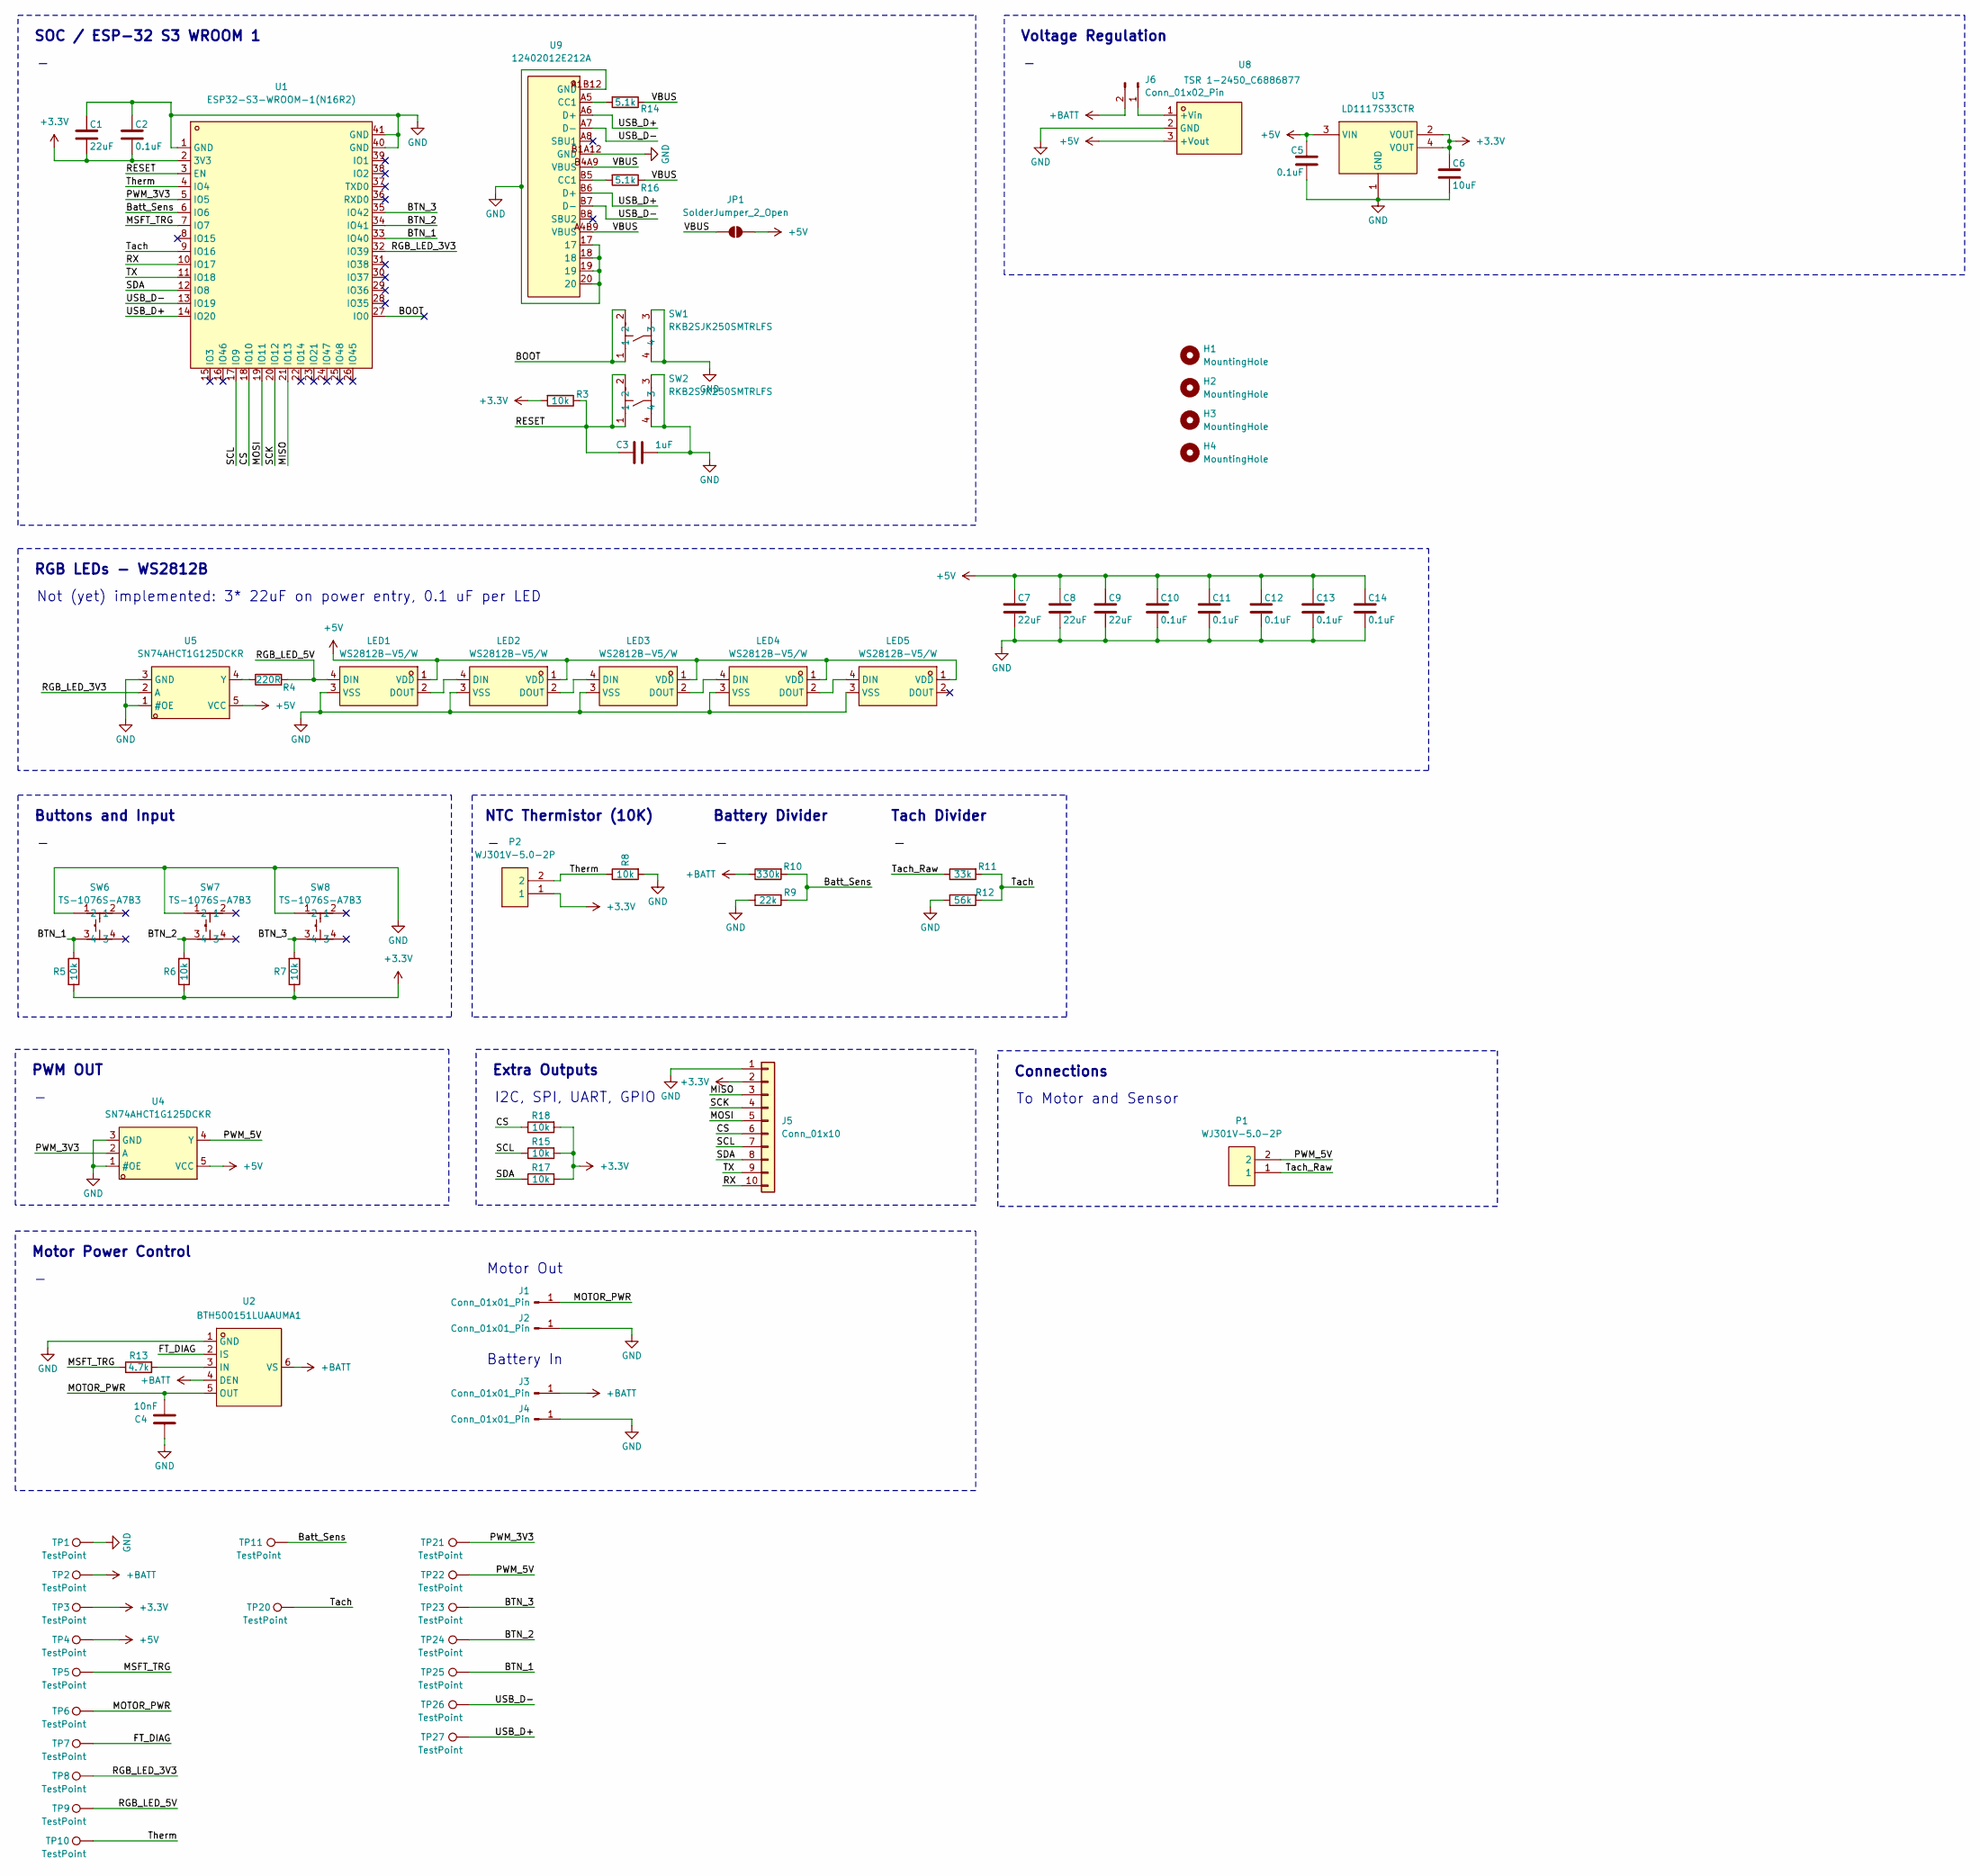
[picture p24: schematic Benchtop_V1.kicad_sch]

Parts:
C1, C7, C8, C9: 22uF; R_0805_2012Metric_Pad1.20x1.40mm_HandSolder
C2, C5, C10, C11, C12, C13, C14: 0.1uF; R_0805_2012Metric_Pad1.20x1.40mm_HandSolder
C3: 1uF; R_0805_2012Metric_Pad1.20x1.40mm_HandSolder
C4: 10nF; R_0805_2012Metric_Pad1.20x1.40mm_HandSolder
C6: 10uF; R_0805_2012Metric_Pad1.20x1.40mm_HandSolder
H1, H2, H3, H4: MountingHole; MountingHole_3.2mm_M3_Pad_Via
J1, J2, J3, J4: Conn_01x01_Pin; SolderWirePad_1x01_SMD_5x10mm
J5: Conn_01x10; PinHeader_2x05_P2.54mm_Vertical
J6: Conn_01x02_Pin; PinHeader_1x02_P2.54mm_Vertical
JP1: SolderJumper_2_Open; SolderJumper-2_P1.3mm_Open_Pad1.0x1.5mm
LED1, LED2, LED3, LED4, LED5: WS2812B-V5/W; LED-SMD_4P-L5.0-W5.0-TL-1; LCSC Part C2874885
P1, P2: WJ301V-5.0-2P; CONN-TH_2P-P5.00_WJ301V-5.00-2P; LCSC Part C8475
R3, R5, R6, R7, R8, R15, R17, R18: 10k; R_0805_2012Metric_Pad1.20x1.40mm_HandSolder
R4: 220R; R_0805_2012Metric_Pad1.20x1.40mm_HandSolder
R9: 22k; R_0805_2012Metric_Pad1.20x1.40mm_HandSolder
R10: 330k; R_0805_2012Metric_Pad1.20x1.40mm_HandSolder
R11: 33k; R_0805_2012Metric_Pad1.20x1.40mm_HandSolder
R12: 56k; R_0805_2012Metric_Pad1.20x1.40mm_HandSolder
R13: 4.7k; R_0805_2012Metric_Pad1.20x1.40mm_HandSolder
R14, R16: 5.1k; R_0805_2012Metric_Pad1.20x1.40mm_HandSolder
SW1, SW2: RKB2SJK250SMTRLFS; SW-SMD_4P-L4.2-W3.2-P2.15-LS4.6; LCSC Part C2927789
SW6, SW7, SW8: TS-1076S-A7B3; KEY-SMD_4P-L5.2-W5.2-P3.7-LS6.4-TL; LCSC Part C492950
TP1, TP2, TP3, TP4, TP5, TP6, TP7, TP8, TP9, TP10, TP11, TP20, TP21, TP22, TP23, TP24, TP25, TP26, TP27: TestPoint; TestPoint_Pad_D1.0mm
U1: ESP32-S3-WROOM-1(N16R2); WIRELM-SMD_ESP32-S3-WROOM-1; LCSC Part C2913205
U2: BTH500151LUAAUMA1; PG-HSOF-8_L10.4-W9.8-BTH500151LUAAUMA1; LCSC Part C36571656
U3: LD1117S33CTR; SOT-223-4_L6.5-W3.5-P2.30-LS7.0-BR; LCSC Part C35879
U4, U5: SN74AHCT1G125DCKR; SC-70-5_L2.0-W1.3-P0.65-LS2.1-BL; LCSC Part C350557
U8: TSR 1-2450_C6886877; PWRM-TH_L11.7-W7.5_TSR1-2450; LCSC Part C6886877
U9: 12402012E212A; USB-SMD_TYPE-C16PIN-1; LCSC Part C5150972

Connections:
+3.3V: C1.2, C2.2, C6.1, J5.2, P2.1, R3.2, R5.2, R6.1, R7.1, R15.2, R17.2, R18.2, TP3.1, U1.2 (3V3), U3.2 (VOUT), U3.4 (VOUT)
+5V: C5.1, C7.1, C8.1, C9.1, C10.1, C11.1, C12.1, C13.1, C14.1, JP1.2 (B), LED1.1 (VDD), LED2.1 (VDD), LED3.1 (VDD), LED4.1 (VDD), LED5.1 (VDD), TP4.1, U3.3 (VIN), U4.5 (VCC), U5.5 (VCC), U8.3 (+Vout)
+BATT: J3.1, J6.2, R10.1, TP2.1, U2.4 (DEN), U2.6 (VS)
/BOOT: SW1.1, SW1.2, U1.27 (IO0)
/BTN_1: R5.1, SW6.3, TP25.1, U1.33 (IO40)
/BTN_2: R6.2, SW7.3, TP24.1, U1.34 (IO41)
/BTN_3: R7.2, SW8.3, TP23.1, U1.35 (IO42)
/Batt_Sens: R9.2, R10.2, TP11.1, U1.6 (IO6)
/CS: J5.6, R18.1, U1.18 (IO10)
/FT_DIAG: TP7.1, U2.2 (IS)
/MISO: J5.3, U1.21 (IO13)
/MOSI: J5.5, U1.19 (IO11)
/MOTOR_PWR: C4.2, J1.1, TP6.1, U2.5 (OUT)
/MSFT_TRG: R13.1, TP5.1, U1.7 (IO7)
/PWM_3V3: TP21.1, U1.5 (IO5), U4.2 (A)
/PWM_5V: P1.2, TP22.1, U4.4 (Y)
/RESET: C3.1, R3.1, SW2.1, SW2.2, U1.3 (EN)
/RGB_LED_3V3: TP8.1, U1.32 (IO39), U5.2 (A)
/RGB_LED_5V: LED1.4 (DIN), R4.2, TP9.1
/RX: J5.10, U1.10 (IO17)
/SCK: J5.4, U1.20 (IO12)
/SCL: J5.7, R15.1, U1.17 (IO9)
/SDA: J5.8, R17.1, U1.12 (IO8)
/TX: J5.9, U1.11 (IO18)
/Tach: R11.2, R12.2, TP20.1, U1.9 (IO16)
/Tach_Raw: P1.1, R11.1
/Therm: P2.2, R8.1, TP10.1, U1.4 (IO4)
/USB_D+: TP27.1, U1.14 (IO20), U9.A6 (D+), U9.B6 (D+)
/USB_D-: TP26.1, U1.13 (IO19), U9.A7 (D-), U9.B7 (D-)
/VBUS: JP1.1 (A), R14.1, R16.1, U9.A4B9 (VBUS), U9.B4A9 (VBUS)
GND: C1.1, C2.1, C3.2, C4.1, C5.2, C6.2, C7.2, C8.2, C9.2, C10.2, C11.2, C12.2, C13.2, C14.2, J2.1, J4.1, J5.1, LED1.3 (VSS), LED2.3 (VSS), LED3.3 (VSS), LED4.3 (VSS), LED5.3 (VSS), R8.2, R9.1, R12.1, SW1.3, SW1.4, SW2.3, SW2.4, SW6.1, SW7.1, SW8.1, TP1.1, U1.1 (GND), U1.40 (GND), U1.41 (GND), U2.1 (GND), U3.1 (GND), U4.1 (#OE), U4.3 (GND), U5.1 (#OE), U5.3 (GND), U8.2 (GND), U9.17, U9.18, U9.19, U9.20, U9.A1B12 (GND), U9.B1A12 (GND)
unnamed: J6.1, U8.1 (+Vin)
unnamed: LED1.2 (DOUT), LED2.4 (DIN)
unnamed: LED2.2 (DOUT), LED3.4 (DIN)
unnamed: LED3.2 (DOUT), LED4.4 (DIN)
unnamed: LED4.2 (DOUT), LED5.4 (DIN)
unnamed: R14.2, U9.A5 (CC1)
unnamed: R16.2, U9.B5 (CC1)
unnamed: R13.2, U2.3 (IN)
unnamed: R4.1, U5.4 (Y)

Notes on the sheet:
PWM OUT
NTC Thermistor (10K)
Buttons and Input
Extra Outputs
Voltage Regulation
Motor Out
RGB LEDs - WS2812B
To Motor and Sensor
SOC / ESP-32 S3 WROOM 1
Motor Power Control
Not (yet) implemented: 3* 22uF on power entry, 0.1 uF per LED
Battery Divider
Battery In
I2C, SPI, UART, GPIO
Connections
Tach Divider

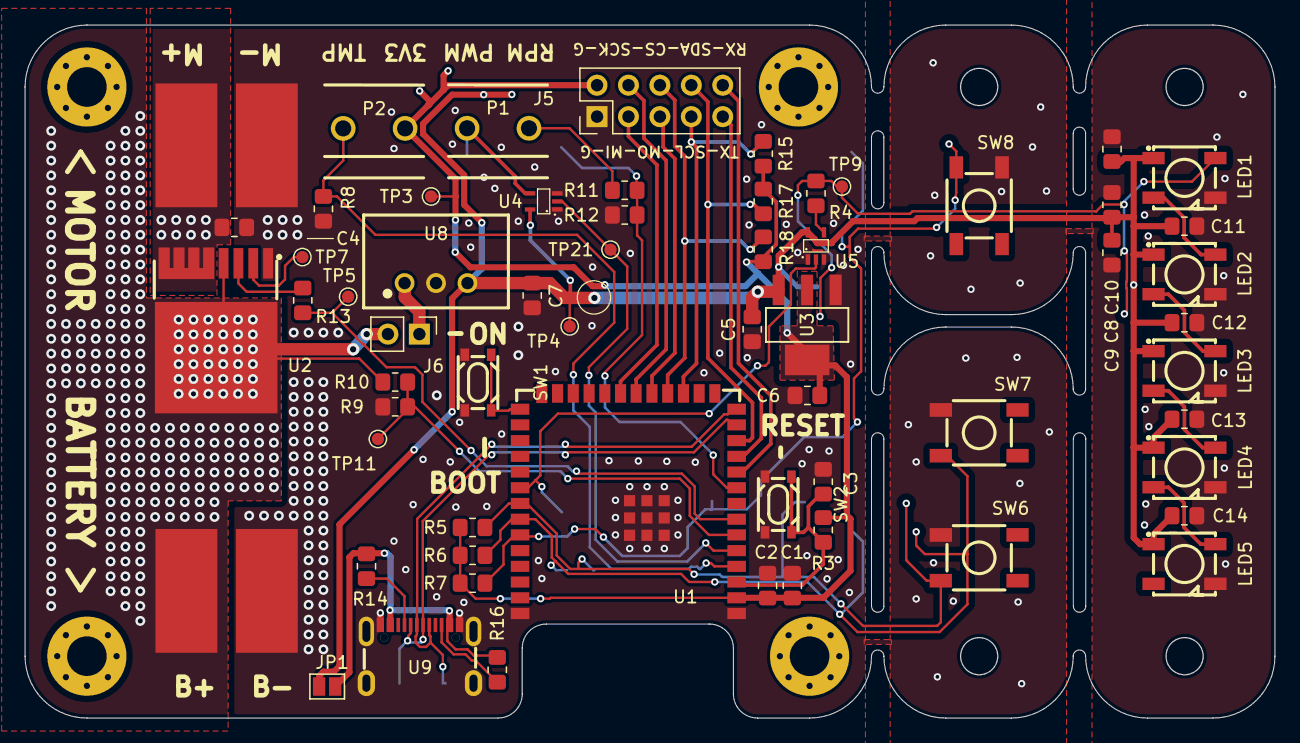
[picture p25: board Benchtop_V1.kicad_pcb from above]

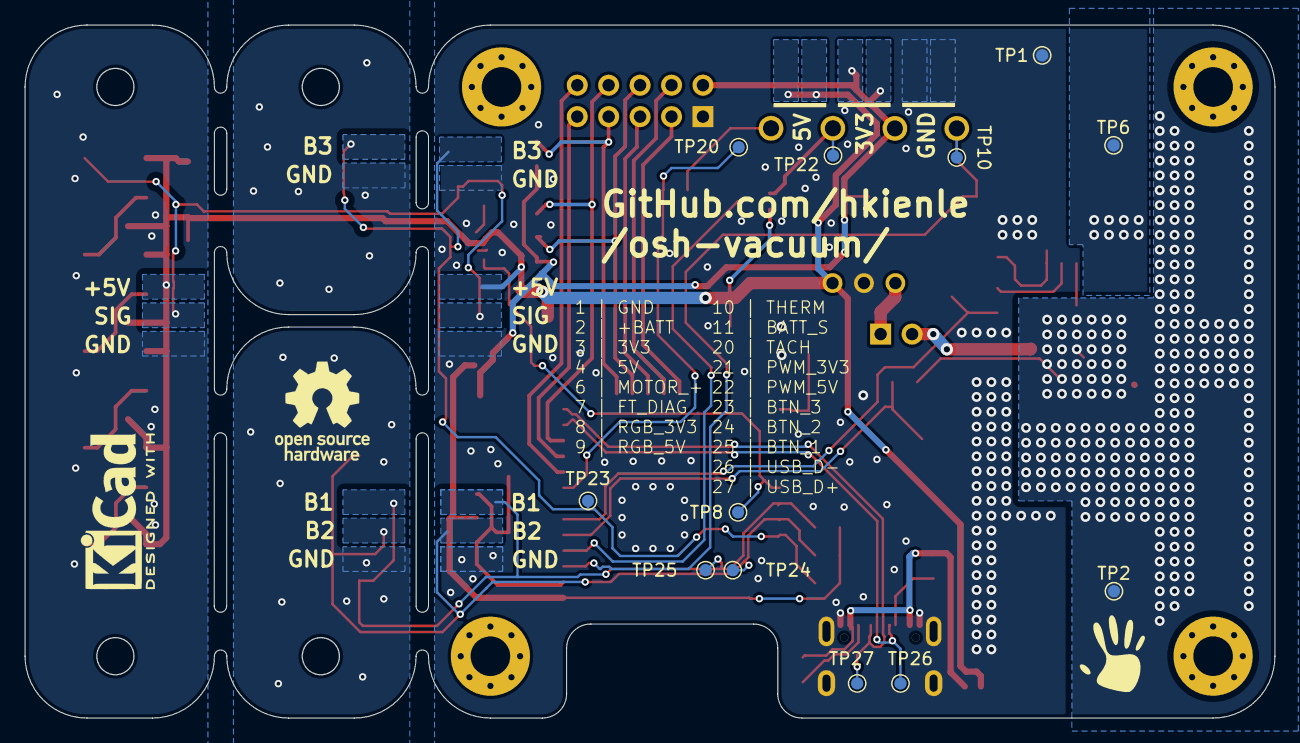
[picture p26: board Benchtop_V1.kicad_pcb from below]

Board: 2 copper layers, 101.0 x 56.0 mm, 79 parts (12 on the bottom side), 40 nets.

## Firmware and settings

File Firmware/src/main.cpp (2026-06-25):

#include <Arduino.h>
#include <ESP.h>
#include <stdio.h>
#include "wifi/wifi.h"
#include "led/led.h"
#include "temperature/temperature.h"
#include "battery/battery.h"
#include "battery_soc/battery_soc.h"
#include "tachometer/tachometer.h"
#include "websocket/websocket.h"
#include "device_link/device_link.h"
#include "device_protocol/device_protocol.h"
#include "motor/motor.h"
#include "webserver/webserver.h"
#include "ota/ota.h"
#include "button/button.h"
#include "settings/settings.h"
#include "settings/settings_config.h"
#include "settings/dev_menu.h"
#include "display/display.h"
#include "mcu_temp/mcu_temp.h"
#include "power/power.h"
#include "maximum_stats/maximum_stats.h"

long nextBroadcastTime = 0;
int broadcastInterval = 250;

namespace {
void onRuntimeSettingsChanged(const RuntimeSettings& settings) {
  applyDisplayContrast(settings.displayContrastPercent);
  deviceLinkRequestSettingsBroadcast();
}
}  // namespace

void setup() {
  // Pull IO7 low (will be controlled by button module)
  pinMode(7, OUTPUT);
  digitalWrite(7, LOW);

  // Black out WS2812 as early as possible (before USB wait) so they stay off until boot glow.
  initLED();

  Serial.begin(115200);
  delay(1000);  // Blocking wait only in setup() (Serial/USB attach)

  initButtons();
  initTemperature();
  initBattery();
  initTachometer();
#ifndef OSHVAC_BLE_PRIMARY
  initWebServer();
#endif
  initOTA();
  setupWiFi();
  deviceLinkInit();
  initSettings();
  loadRuntimeSettings();
  setRuntimeSettingsChangedCallback(onRuntimeSettingsChanged);
  initMotor(getRuntimeSettings().motorType);
  devMenuRebuildVisible();
  initMaximumStats();
  initBatterySOC(getRuntimeSettings().batterySeriesCells);
  initDisplay(getRuntimeSettings());
  initMcuTemperature();
  initPowerManagement();
  // Optional settle time for 1.5" splash (blocking only allowed in setup()).
  if (getRuntimeSettings().displayType == DisplayType::Waveshare15I2C) {
    delay(100);
  }

  printNetworkSummaryToSerial();
  enableLEDBarDisplay(static_cast<uint8_t>(getRuntimeSettings().ledTheme));
}

void loop() {
  static uint32_t motorRunStartMs = 0;
  static uint32_t undervoltageBelowSinceMs = 0;

  // Update buttons (handles speed changes and trigger state)
  updateButtons();
  
  if (isMotorActive()) {
    const uint8_t speed = getSpeed();
    setMotorSpeedPercent(speed);
    startMotor();
    if (motorRunStartMs == 0) {
      motorRunStartMs = millis();
    }
  } else {
    // Motor is stopped: stop PWM output
    stopMotor();
    motorRunStartMs = 0;
  }
  
  updateTemperature();
  updateMcuTemperature();
  updateBattery();
  updateBatterySOC();
  updateTachometer();
  updateOTA();

  maximumStatsOnMotorLoop(
      isMotorActive(),
      motorGetRpm(),
      motorIsRpmReady(),
      getBatteryVoltage(),
      getTemperature(),
      isTemperatureReady());

  {
    const RuntimeSettings& rsLed = getRuntimeSettings();
    const MaximumStatsForDisplay mxLed = maximumStatsGetForDisplay();
    updateLEDBarGraph(
        getBatterySOC(),
        motorGetRpm(),
        motorIsRpmReady(),
        mxLed.maxRpm,
        mxLed.hasMaxRpm,
        getSpeed(),
        getTemperature(),
        isTemperatureReady(),
        rsLed.tempLimitC,
        isMotorActive(),
        static_cast<uint8_t>(rsLed.ledIdleDisplayMode),
        static_cast<uint8_t>(rsLed.ledDisplayMode),
        rsLed.ledDimPercent,
        static_cast<uint8_t>(rsLed.ledTheme),
        isOtaUpdateActive(),
        getOtaProgressPercent());
  }
  updateLED();

  if (isMotorActive()) {
    const uint8_t autoOffMin = getRuntimeSettings().autoOffMinutes;
    if (autoOffMin > 0 && motorRunStartMs != 0) {
      const uint32_t runElapsedMs = millis() - motorRunStartMs;
      const uint32_t autoOffMs = static_cast<uint32_t>(autoOffMin) * 60UL * 1000UL;
      if (runElapsedMs >= autoOffMs) {
        setMotorState(false);
        motorRunStartMs = 0;
        Serial.printf("[Main] Motor stopped: auto-off after %u min\n", static_cast<unsigned>(autoOffMin));
        if (deviceLinkHasActiveClients()) {
          String notifyJson;
          char text[96];
          snprintf(text,
                   sizeof(text),
                   "Motor stopped: auto-off after %u min",
                   static_cast<unsigned>(autoOffMin));
          deviceProtocolBuildNotifyJson(notifyJson, "auto_off", text, "info");
          deviceLinkBroadcast(notifyJson.c_str());
        }
      }
    }

    const uint8_t lim = getRuntimeSettings().tempLimitC;
    if (lim > 0 && isTemperatureReady() && getTemperature() > static_cast<float>(lim)) {
      setMotorState(false);
      motorRunStartMs = 0;
      triggerThermalOffBlink();
      Serial.printf("[Main] Motor stopped: NTC > %u C\n", static_cast<unsigned>(lim));
      if (deviceLinkHasActiveClients()) {
        String notifyJson;
        char text[96];
        snprintf(text,
                 sizeof(text),
                 "Motor stopped due to over-temperature (limit %u °C)",
                 static_cast<unsigned>(lim));
        deviceProtocolBuildNotifyJson(notifyJson, "thermal_stop", text, "warning");
        deviceLinkBroadcast(notifyJson.c_str());
      }
    }

    const uint8_t cells = getRuntimeSettings().batterySeriesCells;
    if (cells > 0) {
      const float packV = getBatteryVoltage();
      if (packV > 0.05f) {
        const float cellV = packV / static_cast<float>(cells);
        const float minCellV = SettingsConfig::DEFAULT_MIN_CELL_VOLTAGE_CUTOFF;
        if (cellV < minCellV) {
          const uint32_t now = millis();
          if (undervoltageBelowSinceMs == 0) {
            undervoltageBelowSinceMs = now;
          } else if ((now - undervoltageBelowSinceMs) >= 400) {
            setMotorState(false);
            motorRunStartMs = 0;
            undervoltageBelowSinceMs = 0;
            Serial.printf("[Main] Motor stopped: pack undervoltage (%.2f V, %.2f V/cell)\n",
                          static_cast<double>(packV),
                          static_cast<double>(cellV));
            if (deviceLinkHasActiveClients()) {
              String notifyJson;
              char text[96];
              snprintf(text,
                       sizeof(text),
                       "Motor stopped: battery undervoltage (%.2f V, %.2f V/cell)",
                       static_cast<double>(packV),
                       static_cast<double>(cellV));
              deviceProtocolBuildNotifyJson(notifyJson, "undervoltage_stop", text, "warning");
              deviceLinkBroadcast(notifyJson.c_str());
            }
          }
        } else {
          undervoltageBelowSinceMs = 0;
        }
      }
    }
  } else {
    undervoltageBelowSinceMs = 0;
  }

  const bool buttonActivity = hadButtonActivityAndClear();
  if (updatePowerManagement(buttonActivity, isMotorActive(), isOtaUpdateActive())) {
    return;
  }
  const RuntimeSettings& rs = getRuntimeSettings();
  const MaximumStatsForDisplay mx = maximumStatsGetForDisplay();
  DisplayTelemetry telemetry {
    getSpeed(),
    getBatteryVoltage(),
    getTemperature(),
    isTemperatureReady(),
    getMcuTemperatureC(),
    motorGetRpm(),
    isTriggerPressed(),
    motorIsRpmReady(),
    getBatterySOC(),
    isMotorActive(),
    isDisplayInfoMode(),
    getDisplayInfoPage(),
    static_cast<uint32_t>(millis() / 1000UL),
    ESP.getFreeHeap(),
    rs.batterySeriesCells,
    isOtaUpdateActive(),
    getOtaProgressPercent(),
    rs.autoOffMinutes,
    rs.sleepTimerMinutes,
    rs.tempLimitC,
    rs.speedStepPercent,
    rs.minDutyPercent,
    rs.maxDutyPercent,
    static_cast<uint8_t>(rs.motorDisplayMode),
    static_cast<uint8_t>(rs.triggerMode),
    static_cast<uint8_t>(rs.ledIdleDisplayMode),
    static_cast<uint8_t>(rs.ledDisplayMode),
    rs.ledDimPercent,
    static_cast<uint8_t>(rs.ledTheme),
    static_cast<uint8_t>(rs.motorType),
    mx.maxRpm,
    mx.hasMaxRpm,
    mx.maxVoltageV,
    mx.hasMaxVoltage,
    mx.maxMotorTempC,
    mx.hasMaxMotorTemp,
  };
  updateDisplay(telemetry);
  updateMotor();  // Check heartbeat timeout
#ifndef OSHVAC_BLE_PRIMARY
  updateWebServer();
#endif
  deviceLinkUpdate();

  if (millis() > nextBroadcastTime) {
    const uint8_t speedPercent = getSpeed();
    const float batteryVoltage = getBatteryVoltage();
    const float rpmValue = motorGetRpm();
    const bool motorActive = isMotorActive();

    char serialLine[160];
    snprintf(serialLine, sizeof(serialLine),
             "Temperature: %.2f / Battery: %.2f / RPM: %.0f / Speed: %u%%",
             getTemperature(), batteryVoltage, rpmValue, static_cast<unsigned>(speedPercent));
    Serial.println(serialLine);

    if (deviceLinkHasActiveClients()) {
      String jsonBuffer;
      deviceProtocolBuildTelemetryJson(jsonBuffer,
                                       getTemperature(),
                                       getBatteryVoltage(),
                                       motorGetRpm(),
                                       speedPercent,
                                       motorActive,
                                       getBatterySOC());
      if (jsonBuffer.length() > 0) {
        deviceLinkBroadcast(jsonBuffer.c_str());
      }
    }
    
    nextBroadcastTime = millis() + broadcastInterval;
  }
}

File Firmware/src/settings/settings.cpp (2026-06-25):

#include "settings.h"
#include "settings_config.h"

#include <Preferences.h>
#include <string.h>

namespace {
constexpr char SETTINGS_NAMESPACE[] = "oshvac";
constexpr char KEY_DISPLAY_TYPE[] = "display_type";
constexpr char KEY_BAT_CELLS[] = "bat_cells";
constexpr char KEY_AUTO_OFF[] = "auto_off";
constexpr char KEY_SLEEP_TMR[] = "sleep_tmr";
constexpr char KEY_TEMP_LIM[] = "temp_lim";
constexpr char KEY_SPD_STEP[] = "spd_step";
constexpr char KEY_MIN_DUTY[] = "min_duty";
constexpr char KEY_MAX_DUTY[] = "max_duty";
constexpr char KEY_MTR_DISP[] = "mtr_disp";
constexpr char KEY_TRIG_MODE[] = "trig_mode";
constexpr char KEY_LED_DISP[] = "led_disp";
constexpr char KEY_LED_IDLE[] = "led_idle";
constexpr char KEY_LED_DIM[] = "led_dim";
constexpr char KEY_DISP_CONTRAST[] = "disp_contrast";
constexpr char KEY_LED_THEME[] = "led_theme";
constexpr char KEY_MTR_TYPE[] = "mtr_type";
constexpr char DISPLAY_091[] = "0.91-I2C-Waveshare";
constexpr char DISPLAY_15[] = "1.5-I2C-Waveshare";
constexpr char DISPLAY_NONE[] = "none";

static RuntimeSettings s_rt;
static RuntimeSettingsChangedCallback s_changedCallback = nullptr;

uint8_t clampAutoOff(uint8_t v) {
  if (v == 0 || v == 1 || v == 2 || v == 5 || v == 10 || v == 30) {
    return v;
  }
  return SettingsConfig::DEFAULT_AUTO_OFF_MINUTES;
}

uint8_t clampTempLim(uint8_t v) {
  if (v == 0 || (v >= 30 && v <= 70 && (v % 5) == 0)) {
    return v;
  }
  return SettingsConfig::DEFAULT_TEMP_LIMIT_C;
}

uint8_t clampSleepTimer(uint8_t v) {
  if (v == 1 || v == 2 || v == 5 || v == 10 || v == 30) {
    return v;
  }
  return SettingsConfig::DEFAULT_SLEEP_TIMER_MINUTES;
}

uint8_t clampSpeedStep(uint8_t v) {
  if (v == 1 || v == 5 || v == 10 || v == 20 || v == 25) {
    return v;
  }
  return SettingsConfig::DEFAULT_SPEED_STEP_PERCENT;
}

uint8_t clampMinDuty(uint8_t v) {
  if (v == 0 || (v >= 1 && v <= 30)) {
    return v;
  }
  return SettingsConfig::DEFAULT_MIN_DUTY_PERCENT;
}

MotorDisplayMode clampMotorDisp(uint8_t v) {
  if (v <= static_cast<uint8_t>(MotorDisplayMode::MotorTemp)) {
    return static_cast<MotorDisplayMode>(v);
  }
  return static_cast<MotorDisplayMode>(SettingsConfig::DEFAULT_MOTOR_DISPLAY_MODE);
}

TriggerMode clampTriggerMode(uint8_t v) {
  if (v <= static_cast<uint8_t>(TriggerMode::DoublePress)) {
    return static_cast<TriggerMode>(v);
  }
  return static_cast<TriggerMode>(SettingsConfig::DEFAULT_TRIGGER_MODE);
}

LedDisplayMode clampLedDisp(uint8_t v) {
  if (v <= static_cast<uint8_t>(LedDisplayMode::Temp)) {
    return static_cast<LedDisplayMode>(v);
  }
  return static_cast<LedDisplayMode>(SettingsConfig::DEFAULT_LED_DISPLAY_MODE);
}

LedIdleDisplayMode clampLedIdle(uint8_t v) {
  if (v <= static_cast<uint8_t>(LedIdleDisplayMode::Rpm)) {
    return static_cast<LedIdleDisplayMode>(v);
  }
  return static_cast<LedIdleDisplayMode>(SettingsConfig::DEFAULT_LED_IDLE_DISPLAY_MODE);
}

uint8_t clampLedDimPercent(uint8_t v) {
  if (v <= 10) {
    return v;
  }
  if (v >= 15 && v <= 50 && (v - 15) % 5 == 0) {
    return v;
  }
  return SettingsConfig::DEFAULT_LED_DIM_PERCENT;
}

uint8_t clampDisplayContrastPercent(uint8_t v) {
  if (v >= 10 && v <= 100 && (v % 10) == 0) {
    return v;
  }
  return SettingsConfig::DEFAULT_DISPLAY_CONTRAST_PERCENT;
}

LedTheme clampLedTheme(uint8_t v) {
  if (v <= static_cast<uint8_t>(LedTheme::Yellow)) {
    return static_cast<LedTheme>(v);
  }
  return static_cast<LedTheme>(SettingsConfig::DEFAULT_LED_THEME);
}

MotorType clampMotorType(uint8_t v) {
  if (v <= static_cast<uint8_t>(MotorType::XiaomiG)) {
    return static_cast<MotorType>(v);
  }
  return static_cast<MotorType>(SettingsConfig::DEFAULT_MOTOR_TYPE);
}
}  // namespace

uint8_t maxDutyPercentLowerBound(uint8_t minDutyPercent) {
  uint8_t m = minDutyPercent;
  if (!(m == 0 || (m >= 1 && m <= 30))) {
    m = SettingsConfig::DEFAULT_MIN_DUTY_PERCENT;
  }
  uint8_t lo = 50;
  const unsigned need = static_cast<unsigned>(m) + 1U;
  if (need > static_cast<unsigned>(lo)) {
    lo = static_cast<uint8_t>(need > 100U ? 100U : need);
  }
  return lo;
}

uint8_t clampMaxDutyPercent(uint8_t maxDutyPercent, uint8_t minDutyPercent) {
  const uint8_t lo = maxDutyPercentLowerBound(minDutyPercent);
  if (maxDutyPercent < lo) {
    return lo;
  }
  if (maxDutyPercent > 100) {
    return 100;
  }
  return maxDutyPercent;
}

void initSettings() {}

DisplayType parseDisplayType(const char* value) {
  if (value == nullptr || value[0] == '\0') {
    return DisplayType::Waveshare091I2C;
  }

  if (strcmp(value, DISPLAY_091) == 0) {
    return DisplayType::Waveshare091I2C;
  }
  if (strcmp(value, DISPLAY_15) == 0) {
    return DisplayType::Waveshare15I2C;
  }
  if (strcmp(value, DISPLAY_NONE) == 0) {
    return DisplayType::None;
  }

  return DisplayType::Waveshare091I2C;
}
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

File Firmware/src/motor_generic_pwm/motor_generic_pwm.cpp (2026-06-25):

#include "motor_generic_pwm.h"

#include <Arduino.h>
#include <string.h>

#include "../settings/settings.h"
#include "../tachometer/tachometer.h"

namespace {
constexpr uint8_t PWM_PIN = 5;
constexpr int PWM_RES_BITS = 8;
constexpr int PWM_FREQ_HZ = 1000;

static int duty = 0;
static bool running = false;
static bool pinAttached = false;

// Speed-level synthesis (max 101 steps if step==1)
constexpr uint8_t kMaxSynthLevels = 101;
static MotorSpeedLevel s_levels[kMaxSynthLevels];
static char s_levelLabels[kMaxSynthLevels][12];

void applyDutyFromSpeedPercent(uint8_t speedPct) {
  const uint8_t minP = getRuntimeSettings().minDutyPercent;
  const uint8_t maxP = clampMaxDutyPercent(getRuntimeSettings().maxDutyPercent, minP);
  int pwmDuty = 0;
  if (speedPct > 0) {
    const int minDuty = static_cast<int>((minP * 255) / 100);
    const int maxDuty = static_cast<int>((maxP * 255) / 100);
    pwmDuty = minDuty + (static_cast<int>(speedPct) * (maxDuty - minDuty)) / 100;
  }
  motorGenericPwmSetDuty(pwmDuty);
}

void pwmInit() {
  running = false;
  duty = 0;
  pinAttached = false;
  pinMode(PWM_PIN, OUTPUT);
  digitalWrite(PWM_PIN, LOW);
}

void pwmDeinit() {
  motorGenericPwmStop();
}

void pwmUpdate() {}

void pwmOnPowerOn() {}

void pwmOnPowerOff() {}

void pwmSetSpeedPercent(uint8_t percent) {
  if (percent > 100) {
    percent = 100;
  }
  applyDutyFromSpeedPercent(percent);
}

bool pwmIsRunning() {
  return running;
}

float pwmGetRpm() {
  return getRPM();
}

bool pwmIsRpmReady() {
  return isRPMReady();
}

MotorSpeedLevels pwmGetSpeedLevels(uint8_t configuredStepPct, uint8_t /*minDutyPct*/, uint8_t /*maxDutyPct*/) {
  uint8_t step = configuredStepPct;
  if (step == 0) {
    step = 20;
  }
  uint8_t n = 0;
  for (unsigned v = 0; v <= 100 && n < kMaxSynthLevels; v += step) {
    snprintf(s_levelLabels[n], sizeof(s_levelLabels[n]), "%u %%", static_cast<unsigned>(v));
    s_levels[n].valuePercent = static_cast<uint8_t>(v);
    s_levels[n].label = s_levelLabels[n];
    ++n;
  }
  if (n > 0 && s_levels[n - 1].valuePercent < 100) {
    snprintf(s_levelLabels[n], sizeof(s_levelLabels[n]), "100 %%");
    s_levels[n].valuePercent = 100;
    s_levels[n].label = s_levelLabels[n];
    ++n;
  }
  return MotorSpeedLevels{n, s_levels};
}

void pwmHandleWsCommand(const char* key, int value) {
  if (strcmp(key, "speed") != 0) {
    return;
  }
  int speed = value;
  if (speed < 0) {
    speed = 0;
  }
  if (speed > 255) {
    speed = 255;
  }
  Serial.printf("[Motor] Setting speed to %d\n", speed);
  if (speed == 0) {
    motorGenericPwmStop();
    Serial.println("[Motor] Motor stopped");
  } else {
    motorGenericPwmSetDuty(speed);
    motorGenericPwmStart();
    Serial.printf("[Motor] Motor started at duty %d\n", speed);
  }
}

void pwmHandleHeartbeat() {}

bool pwmSupportsGlobal(DevSettingId /*id*/) {
  return true;
}

MotorDriverSettings pwmDriverSettings() {
  return MotorDriverSettings{0, nullptr};
}

}  // namespace

void motorGenericPwmSetDuty(int newDuty) {
  if (newDuty < 0) {
    newDuty = 0;
  }
  if (newDuty > 255) {
    newDuty = 255;
  }
  duty = newDuty;
  if (duty == 0) {
    if (pinAttached) {
      ledcDetach(PWM_PIN);
      pinAttached = false;
    }
    pinMode(PWM_PIN, OUTPUT);
    digitalWrite(PWM_PIN, LOW);
    running = false;
  } else {
    if (!pinAttached) {
      ledcAttach(PWM_PIN, PWM_FREQ_HZ, PWM_RES_BITS);
      pinAttached = true;
    }
    if (running) {
      ledcWrite(PWM_PIN, duty);
    }
  }
}

void motorGenericPwmStart() {
  if (duty > 0 && !pinAttached) {
    ledcAttach(PWM_PIN, PWM_FREQ_HZ, PWM_RES_BITS);
    pinAttached = true;
  }
  running = true;
  if (duty > 0) {
    ledcWrite(PWM_PIN, duty);
  }
}

void motorGenericPwmStop() {
  running = false;
  if (pinAttached) {
    ledcWrite(PWM_PIN, 0);
    ledcDetach(PWM_PIN);
    pinAttached = false;
  }
  pinMode(PWM_PIN, OUTPUT);
  digitalWrite(PWM_PIN, LOW);
}

int motorGenericPwmGetDuty() {
  return duty;
}

bool motorGenericPwmIsRunning() {
  return running;
}

const MotorDriver kGenericPwmDriver = {
    "Generic (PWM)",
    "generic-pwm",
    MotorCapabilities{true, false, false},
    pwmInit,
    pwmDeinit,
    pwmUpdate,
    pwmOnPowerOn,
    pwmOnPowerOff,
    pwmSetSpeedPercent,
    pwmIsRunning,
    pwmGetRpm,
    pwmIsRpmReady,
    pwmGetSpeedLevels,
    pwmHandleWsCommand,
    pwmHandleHeartbeat,
    pwmSupportsGlobal,
    pwmDriverSettings,
};

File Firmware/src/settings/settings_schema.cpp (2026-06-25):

#include "settings_schema.h"

#include <stdio.h>
#include <string.h>

#include "../battery_soc/battery_soc.h"

namespace {
constexpr char KEY_AUTO_OFF[] = "auto_off";
constexpr char KEY_TEMP_LIM[] = "temp_lim";
constexpr char KEY_SPD_STEP[] = "spd_step";
constexpr char KEY_MIN_DUTY[] = "min_duty";
constexpr char KEY_MAX_DUTY[] = "max_duty";
constexpr char KEY_BAT_CELLS[] = "bat_cells";
constexpr char KEY_SLEEP_TMR[] = "sleep_tmr";
constexpr char KEY_TRIG_MODE[] = "trig_mode";
constexpr char KEY_MTR_DISP[] = "mtr_disp";
constexpr char KEY_LED_IDLE[] = "led_idle";
constexpr char KEY_LED_DISP[] = "led_disp";
constexpr char KEY_LED_DIM[] = "led_dim";
constexpr char KEY_DISP_CONTRAST[] = "disp_contrast";
constexpr char KEY_LED_THEME[] = "led_theme";
constexpr char KEY_MTR_TYPE[] = "mtr_type";

constexpr uint8_t kAutoOffValues[] = {0, 1, 2, 5, 10, 30};
constexpr uint8_t kTempValues[] = {0, 30, 35, 40, 45, 50, 55, 60, 65, 70};
constexpr uint8_t kSpeedStepValues[] = {1, 5, 10, 20, 25};
constexpr uint8_t kMinDutyValues[] = {1, 2, 3, 4, 5, 6, 7, 8, 9, 10, 11, 12, 13, 14, 15,
                                      16, 17, 18, 19, 20, 21, 22, 23, 24, 25, 26, 27, 28, 29, 30};
constexpr uint8_t kBatteryCellsValues[] = {1, 2, 3, 4, 5, 6, 7, 8, 9, 10, 11, 12, 13, 14};
constexpr uint8_t kSleepValues[] = {1, 2, 5, 10, 30};
constexpr uint8_t kLedDimValues[] = {0, 1, 2, 3, 4, 5, 6, 7, 8, 9, 10, 15, 20, 25, 30, 35, 40, 45, 50};
constexpr uint8_t kDisplayContrastValues[] = {10, 20, 30, 40, 50, 60, 70, 80, 90, 100};

constexpr SettingEnumOption kTriggerOptions[] = {{static_cast<uint8_t>(TriggerMode::Hold), "Hold"},
                                                 {static_cast<uint8_t>(TriggerMode::DoublePress), "Double-Press"}};
constexpr SettingEnumOption kMotorDispOptions[] = {{static_cast<uint8_t>(MotorDisplayMode::Speed), "Speed"},
                                                   {static_cast<uint8_t>(MotorDisplayMode::Voltage), "Voltage"},
                                                   {static_cast<uint8_t>(MotorDisplayMode::Rpm), "RPM"},
                                                   {static_cast<uint8_t>(MotorDisplayMode::MotorTemp), "MOT Temp"}};
constexpr SettingEnumOption kLedIdleOptions[] = {{static_cast<uint8_t>(LedIdleDisplayMode::Soc), "SOC"},
                                                 {static_cast<uint8_t>(LedIdleDisplayMode::Speed), "Speed"},
                                                 {static_cast<uint8_t>(LedIdleDisplayMode::Rpm), "RPM"}};
constexpr SettingEnumOption kLedDispOptions[] = {{static_cast<uint8_t>(LedDisplayMode::Soc), "SOC"},
                                                 {static_cast<uint8_t>(LedDisplayMode::Rpm), "RPM"},
                                                 {static_cast<uint8_t>(LedDisplayMode::Speed), "Speed"},
                                                 {static_cast<uint8_t>(LedDisplayMode::Temp), "Temp"}};
constexpr SettingEnumOption kThemeOptions[] = {{static_cast<uint8_t>(LedTheme::Off), "Off"},
                                               {static_cast<uint8_t>(LedTheme::White), "White"},
                                               {static_cast<uint8_t>(LedTheme::Blue), "Blue"},
                                               {static_cast<uint8_t>(LedTheme::Green), "Green"},
                                               {static_cast<uint8_t>(LedTheme::Pink), "Pink"},
                                               {static_cast<uint8_t>(LedTheme::Orange), "Orange"},
                                               {static_cast<uint8_t>(LedTheme::Yellow), "Yellow"}};
constexpr SettingEnumOption kMotorTypeOptions[] = {{static_cast<uint8_t>(MotorType::GenericPwm), "Generic (PWM)"},
                                                   {static_cast<uint8_t>(MotorType::XiaomiG), "Xiaomi G"}};
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

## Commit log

2025-11-27 Added KiCad and manufacturing files for the benchtop PCB V1.0
    [Benchtop_V1.kicad_pcb, Benchtop_V1.kicad_sch, bom.csv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]
2026-04-20 add printed parts
    [OSH_Vac_v1.0_BackHandle_Button.step, OSH_Vac_v1.0_BackHandle_LeftHalf.step, OSH_Vac_v1.0_BackHandle_RightHalf.step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]
2026-04-20 moved printfiles into correct dir
    [OSH_Vac_v1.0_BackHandle_Button.step, OSH_Vac_v1.0_BackHandle_LeftHalf.step, OSH_Vac_v1.0_BackHandle_RightHalf.step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]
2026-04-21 added mesh part for the cyclone
    [OSH_Vac_v1.0_Cyclone_Mesh.step]
2026-04-21 Updated Core skrew layout
    [OSH_Vac_v1.0_Core.step, OSH_Vac_v1.1_Core.step]
2026-04-21 Added Holes for different skrew length in lid
    [OSH_Vac_v1.1_Core.step, OSH_Vac_v1.2_Core.step]
2026-04-27 added flat nozzle variants
    [OSH_Vac_v1.0_Nozzle_Flat-d32-w100.step, OSH_Vac_v1.0_Nozzle_Flat-d32-w150.step, OSH_Vac_v1.0_Nozzle_Flat-d32-w200.step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]
2026-04-27 renamed files to match BOM
    [OSH_Vac_core-batteryadapter-parkside_20v-base_v1.step, OSH_Vac_core-batteryadapter-parkside_20v-slot_v1.step, OSH_Vac_core-motoradapter_v1.step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]
2026-04-29 Integrate maximum stats functionality into firmware. Updated display and button handling to support new settings for maximum duty, LED themes, and telemetry. Enhanced LED behavior for OTA updates and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
2026-04-29 First variant of a UART controller.
2026-04-30 added cart and wallmount, moved nozzle to new aux folder
    [OSH_Vac_cart_v1.step, OSH_Vac_nozzle-flat-d32-w100_v1.step, OSH_Vac_nozzle-flat-d32-w150_v1.step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]
2026-04-30 made the cable channel bigger
    [OSH_Vac_dustbin-top_v1.1.step, OSH_Vac_dustbin-top_v1.step]
2026-05-05 removed cable divider in the bottom to avoid pinching
    [OSH_Vac_dustbin-cyclone-bottom_v1.1.step, OSH_Vac_dustbin-cyclone-bottom_v1.step]
2026-05-05 added hose adapter
    [OSH_Vac_dustbin-hoseadapter-bajonett_v1.step, OSH_Vac_dustbin-hoseadapter-siemens_v1.step]
2026-05-13 Add BOM for vacuum component assembly
    Added a Bill of Materials (BOM) for vacuum component assembly, including printed parts, metal hardware, and additional parts with procurement details.
2026-05-22 Change motor behaviour
2026-06-18 switch to 1.5 inch display
2026-06-23 Add WiFi AP provisioning, onboarding tour, and hosted UI deployment.
    Enable saving STA credentials from the Web UI in AP mode with NVS persistence,
    device restart, and AP fallback after a failed connect. Also split settings into
    WebUI/Vac tabs, add device notification toasts, onboarding screenshots, and
    Coolify/Docker config for the hosted app.
    [ble_transport.cpp, device_protocol.cpp, main.cpp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]
2026-06-23 Fix Coolify Nixpacks build on Linux.
    Rename UI component files to lowercase so @/ imports resolve on case-sensitive filesystems, and stop the Vite dev proxy from pulling browser types into the Node tsconfig.
2026-06-23 Fix BLE settings sync truncated by oversized notifications.
    Notifications can only carry ATT_MTU-3 bytes, so the 480-byte chunk payload exceeded the link MTU and silently truncated large messages like the settings schema. Shrink the chunk payload to 180 and request a 247-byte MTU.
    [ble_transport.cpp]
2026-06-23 Fix BLE settings sync with paced TX and no telemetry interleave.
    Send large BLE payloads one fragment per connection interval, queue responses, skip telemetry while TX is busy, and request settings after the WebUI enables notifications.
    [ble_transport.cpp]
2026-06-24 Improve BLE settings sync, transport reliability, and connect UI.
    Cap BLE notifications for macOS compatibility, defer RX handling until the main loop, and add set_settings with schema defaults plus pack undervoltage motor cutoff on the firmware side; align the web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
2026-06-25 Add Test modal with motor ramp and fix live charts for Xiaomi G.
    Replace the battery-only modal with tabbed battery and motor ramp tests, restore live telemetry graphs after the control panel layout change, and use Xiaomi G discrete ESC steps with motor_stop for off.
